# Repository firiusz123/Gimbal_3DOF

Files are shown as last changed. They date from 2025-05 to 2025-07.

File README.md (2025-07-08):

# Gimbal_3DOF

---

## 📖 Project Description

**Gimbal 3DOF** is a three-axis camera stabilization system (pitch, roll, yaw) designed for integration with drones and small aerial platforms. The goal of the project was to create a modular, lightweight, energy-efficient gimball, for the Project classes of AGH university of science and technology course , Mechatronic Design . The system uses an IMU and servos, controlled by an STM32 microcontroller in the custom PCB , and by Arduino Mega within the prototype , both running with FreeRTOS. A Python-based graphical user interface (GUI) is also provided for testing and interaction. The working model present on the provided photos is a prototype that doesnt have the custom PCB that has been designed

---

## ⚙️ Features

- 3-axis stabilization: **Pitch**, **Roll**, and **Yaw**
- Supports cameras up to **200 g**
- Compact size: **30 × 10 × 15 cm**
- Lightweight design: **~200 g**
- Power consumption: **~900 mA** estimated for worst case scenario
- UART-based communication
- Rubber-based vibration damping system
- Python GUI for testing and position control
- FreeRTOS-based multithreaded control system
- Optimized weight distribution and center of mass

---

## 🧾 Requirements

### Hardware with custom PCB

| Component | Model / Notes |
|---|---|
| Microcontroller | STM32G431CBT6 |
| IMU Sensor | IMU 9DOF v2.0 |
| Servos | Feetech FS510R ×3 |
| Oscillator | 8 MHz WE-XTAL |
| PCB | Custom PCB or Arduino prototype  |
| Logic level shifters| 2× SN74LV1T34 |
| Vibration dampers | Silicone-based, hand-cut |

### Hardware of Prototype

| Component | Model / Notes |
|---|---|
| Board | Arduino Mega |
| IMU Sensor | IMU 9DOF v2.0 |
| Servos | Feetech FS510R ×3 |
| LM7805 | 5v Linear Stabilizator |
| 7.4 v lipo | a small lipo battery 2s |

### Connection scheme for the prototype 
#### 🧭 Servo Motor Pinout

| Servo Axis | Signal Pin (Arduino) | VCC (5 V from LM7805) | GND (Common Ground) |
|---|---|---|---|
| Roll | D9 | LM7805 OUT | LM7805 GND |
| Pitch | D10 | LM7805 OUT | LM7805 GND |
| Yaw | D2 | LM7805 OUT | LM7805 GND |

---

### ⚡ Power Supply Setup (LM7805)

| LM7805 Pin | Connects To |
|---|---|
| **IN** | 7.4 V battery (+) |
| **OUT** | - 5 V to all Servo VCC pins  <br> - 5 V to Arduino **VIN** *(optional)* |
| **GND** | - Battery (–) <br> - All Servo GND pins <br> - Arduino **GND** |

The connection from 5v to vin is optional since the power to arduino is also delivered via cable that sends the commands to arduino 

### Software

- FreeRTOS (embedded)
- Python GUI for control and testing
- Source code (C / Arduino)

---

## 💻 Usage

1. Connect all components using the provided PCB or wire manually according to the schematic.
2. Upload the firmware from the `Arduino_example\GimbalControl1` directory to the Arduino.
3. Launch the GUI from the `python_gui` directory for testing and IMU visualization.
4. The gimbal continuously reads IMU data and stabilizes the camera accordingly.
5. You can also send specific positions for the gimbal to hold using the GUI.

---

## 🧩 Hardware & Software

**Hardware:**
- FS510R servos provide accurate positioning with low power consumption.
- IMU 9DOF v2.0 offers compact size, low power, and acceptable precision.
- Custom PCB integrates all components for clean wiring and scalability.
- Silicone dampers mitigate mechanical vibrations from drone operation.

**Software:**
- Based on FreeRTOS – enables independent control of each axis.
- Python GUI allows sending positions, reading IMU data, and system testing.
- All code is available in the `Arduino_example` and `python_gui` directories.

---

## 📈  Simulations

The project included modal simulations (FEM) using Siemens NX. These simulations helped with:

- Identifying modal frequencies (especially around **700 Hz**) and ensuring the control loop (**100 Hz**) avoids them.
- Optimizing the gimbal’s mass distribution and weight balancing.
- Evaluating dynamic response under two critical configurations (extreme pitch/yaw).

Simulation results guided mechanical redesigns and ensured robustness in real-world operation.

---

## 🖼️ Prototype Images

### ✅ Final prototype mounted on a drone:
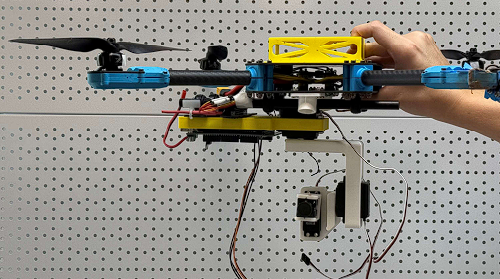
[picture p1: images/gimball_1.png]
Gimbal mounted on drone

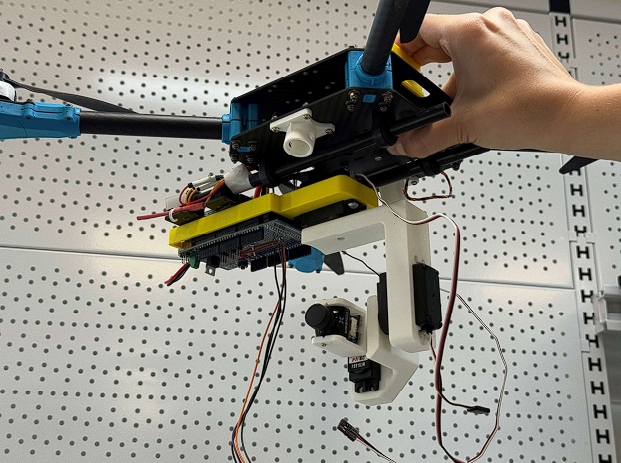
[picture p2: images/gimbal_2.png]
Gimbal mounted on drone

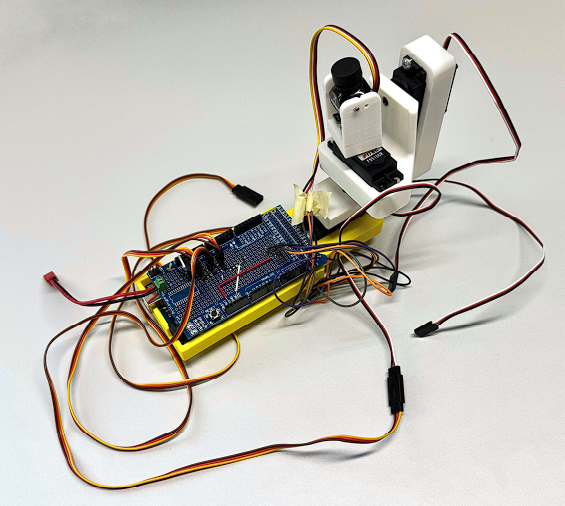
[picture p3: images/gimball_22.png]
Gimbal mounted on drone


### 🛠️ Assembled components:
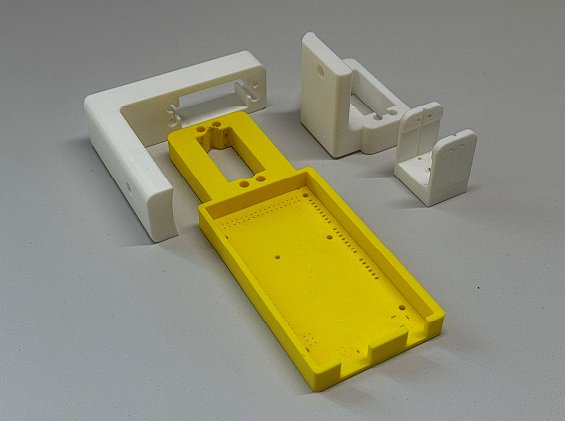
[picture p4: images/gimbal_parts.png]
Gimbal parts


### 🖥️ GUI for testing and visualization:
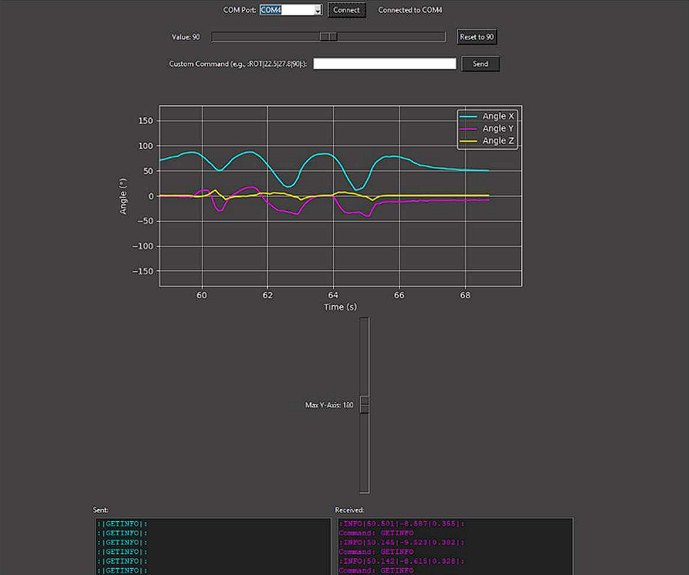
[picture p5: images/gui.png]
GUI


---

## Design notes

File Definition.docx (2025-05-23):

Definition

System for image stabilization and data transfer to higher up hardware in flights

Aspects of the problem:

System functions:

-3dof stabilization

-image acquisition

-image transfer

-water resistance

-dust resistance

-Passive vibration resistance

Properties of 3dof stabilization:

- Type of motors used for movement
- Type of device or devices used for feedback loop
- Control system

Properties of image acquisition:

- Colour range
- Focus
- Resolution
- Dos it include

Properties of image transfer:

- Transfer protocol
- Transfer speed

Properties of Water resistance:

- Grade of water resistance

Properties of dust resistance:

- Grade of dust resistance

Properties of passive vibration resistance:

- Bulletproof

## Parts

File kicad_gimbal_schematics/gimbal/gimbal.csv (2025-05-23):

Reference | Value | Datasheet | Footprint | Qty | DNP
C1,C2,C3 | C | ~ | Capacitor_SMD:C_0805_2012Metric | 3
C4,C5,C6 | 100nF | ~ | Capacitor_SMD:C_0805_2012Metric | 3
C7 | 4.7 μF | ~ | Capacitor_SMD:C_0805_2012Metric | 1
C8 | 10 nF | ~ | Capacitor_SMD:C_0805_2012Metric | 1
C9 | 1 μF | ~ | Capacitor_SMD:C_0805_2012Metric | 1
C10 | 100 nF | ~ | Capacitor_SMD:C_0805_2012Metric | 1
C11 | +1 μF | ~ | Capacitor_SMD:C_0805_2012Metric | 1
C12,C13 | 10 pF | ~ | Capacitor_SMD:C_0805_2012Metric | 2
D1 | D | ~ | Diode_SMD:D_0805_2012Metric | 1
J1 | Conn_01x04_Pin_IMU | ~ | Connector_JST:JST_PH_B4B-PH-K_1x04_P2.00mm_Vertical | 1
J2 | Conn_01x04_Pin | ~ | Connector_JST:JST_PH_B4B-PH-K_1x04_P2.00mm_Vertical | 1
M1,M2,M3 | Motor_Servo | http://forums.parallax.com/uploads/attachments/46831/74481.png | Connector_PinHeader_2.54mm:PinHeader_1x03_P2.54mm_Vertical | 3
R1 | 45Ω | ~ | Resistor_SMD:R_0805_2012Metric | 1
SW1 | SW_Slide_DPDT | ~ | Button_Switch_THT:SW_CK_JS202011CQN_DPDT_Straight | 1
SW3 | SW_Push | ~ | Button_Switch_SMD:SW_Push_1P1T_NO_6x6mm_H9.5mm | 1
U1 | STM32G431CBTx | https://www.st.com/resource/en/datasheet/stm32g431cb.pdf | Package_QFP:LQFP-48_7x7mm_P0.5mm | 1
U2 | LT1761-3.3 | https://www.analog.com/media/en/technical-documentation/data-sheets/1761sff.pdf | Package_TO_SOT_SMD:TSOT-23-5 | 1
U3,U4 | SN74LV1T34DBV | https://www.ti.com/lit/ds/symlink/sn74lv1t34.pdf | Package_TO_SOT_SMD:SOT-23-5 | 2
Y1 | 8 MHz | ~ | Crystal:Crystal_HC18-U_Vertical | 1

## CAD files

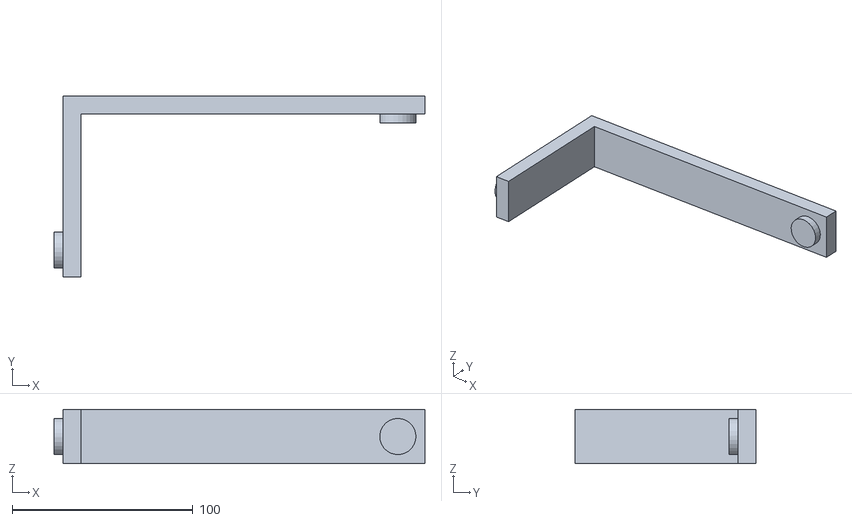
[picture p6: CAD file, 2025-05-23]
Gimbal_initial_simulation/STL_Hell/arm_1.stl
205.0 x 100.0 x 30.0

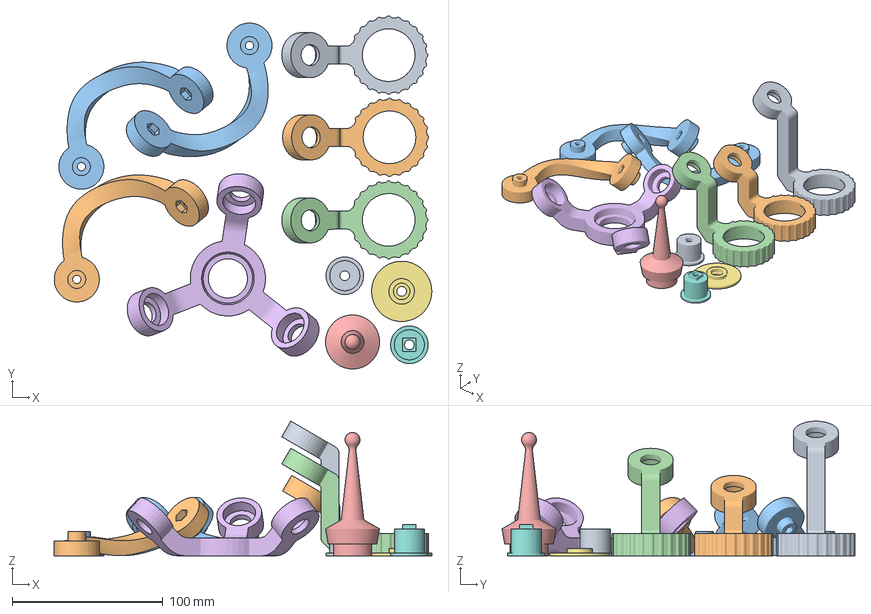
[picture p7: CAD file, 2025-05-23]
SPM_project.3mf
250.7 x 234.5 x 89.5 mm
Arm 1.STL
Arm 3.STL
Arm(x3).STL x 3
Arm 2.STL
Pin.STL
Center Platform.STL
End Plate.STL
Shaft 2.STL
Shaft 3.STL

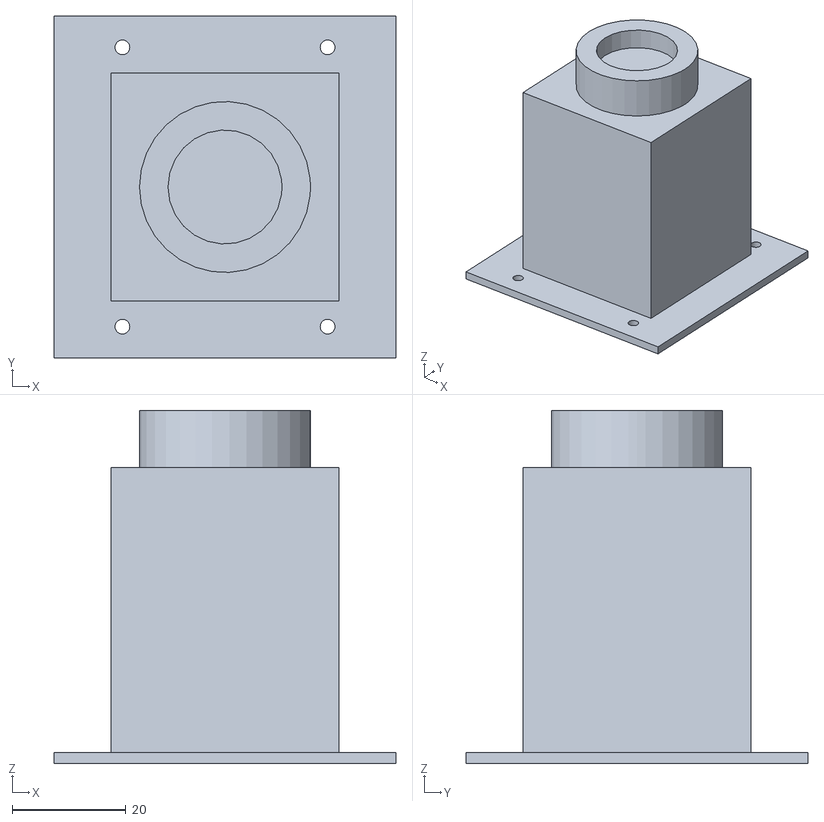
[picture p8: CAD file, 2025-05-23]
Gimbal_initial_simulation/STL_Hell/base.stl
60.0 x 60.0 x 62.0

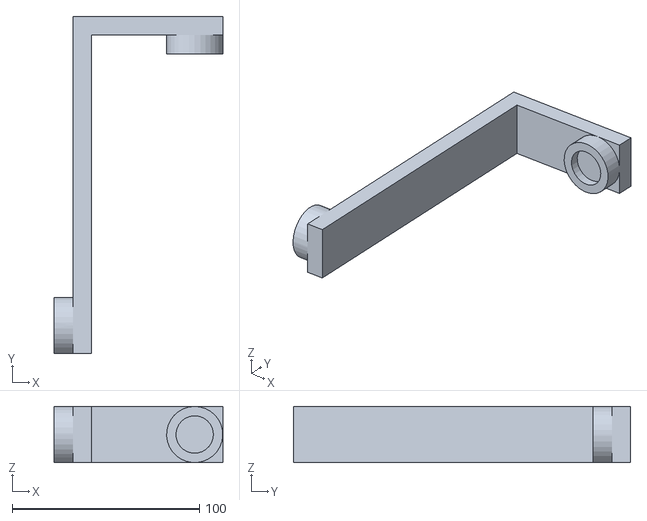
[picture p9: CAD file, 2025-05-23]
Gimbal_initial_simulation/STL_Hell/arm_2.stl
90.0 x 180.0 x 30.0

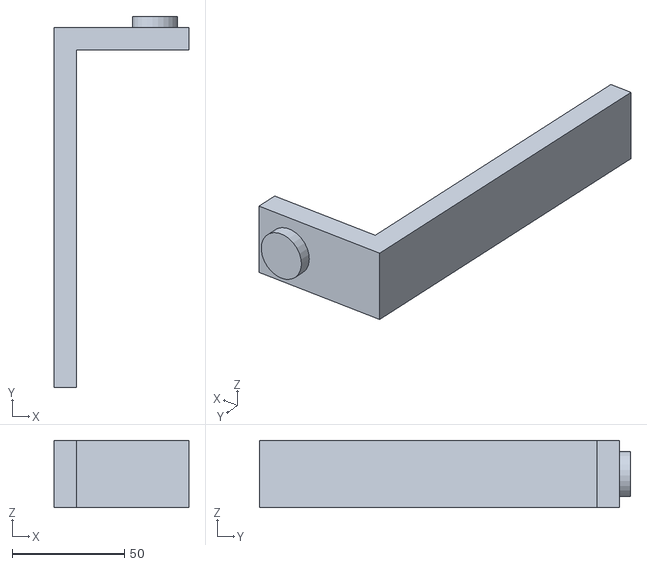
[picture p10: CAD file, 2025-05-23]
Gimbal_initial_simulation/STL_Hell/platform.stl
60.0 x 165.0 x 30.0

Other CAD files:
Fusion 360 Assembly/Gimbal v2.f3z

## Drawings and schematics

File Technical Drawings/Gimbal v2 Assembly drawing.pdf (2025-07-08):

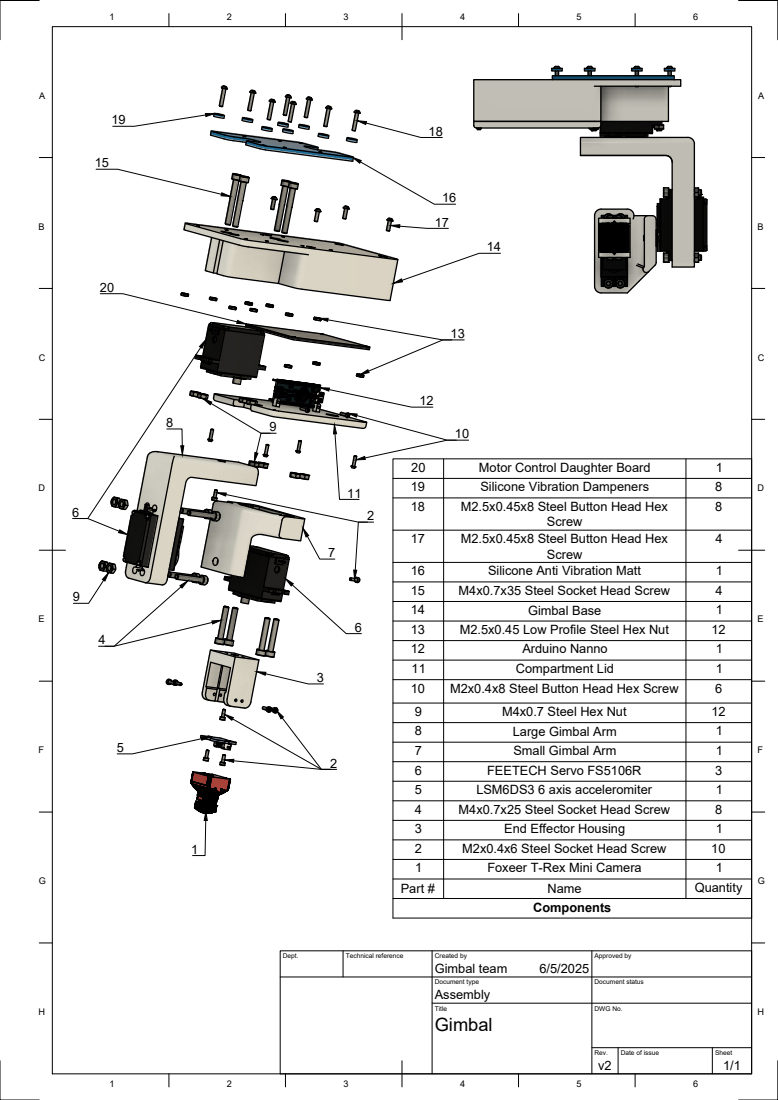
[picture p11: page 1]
Dept.; Technical reference; Created by; Approved by; Document type; Document status; Title; DWG No.; Rev.; Date of issue; Sheet; Gimbal team; Part #; Name; Quantity; Foxeer T-Rex Mini Camera; M2x0.4x6 Steel Socket Head Screw; End Effector Housing; M4x0.7x25 Steel Socket Head Screw; LSM6DS3 6 axis acceleromiter; FEETECH Servo FS5106R; Small Gimbal Arm; Large Gimbal Arm; M4x0.7 Steel Hex Nut; M2x0.4x8 Steel Button Head Hex Screw; Compartment Lid; Arduino Nanno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

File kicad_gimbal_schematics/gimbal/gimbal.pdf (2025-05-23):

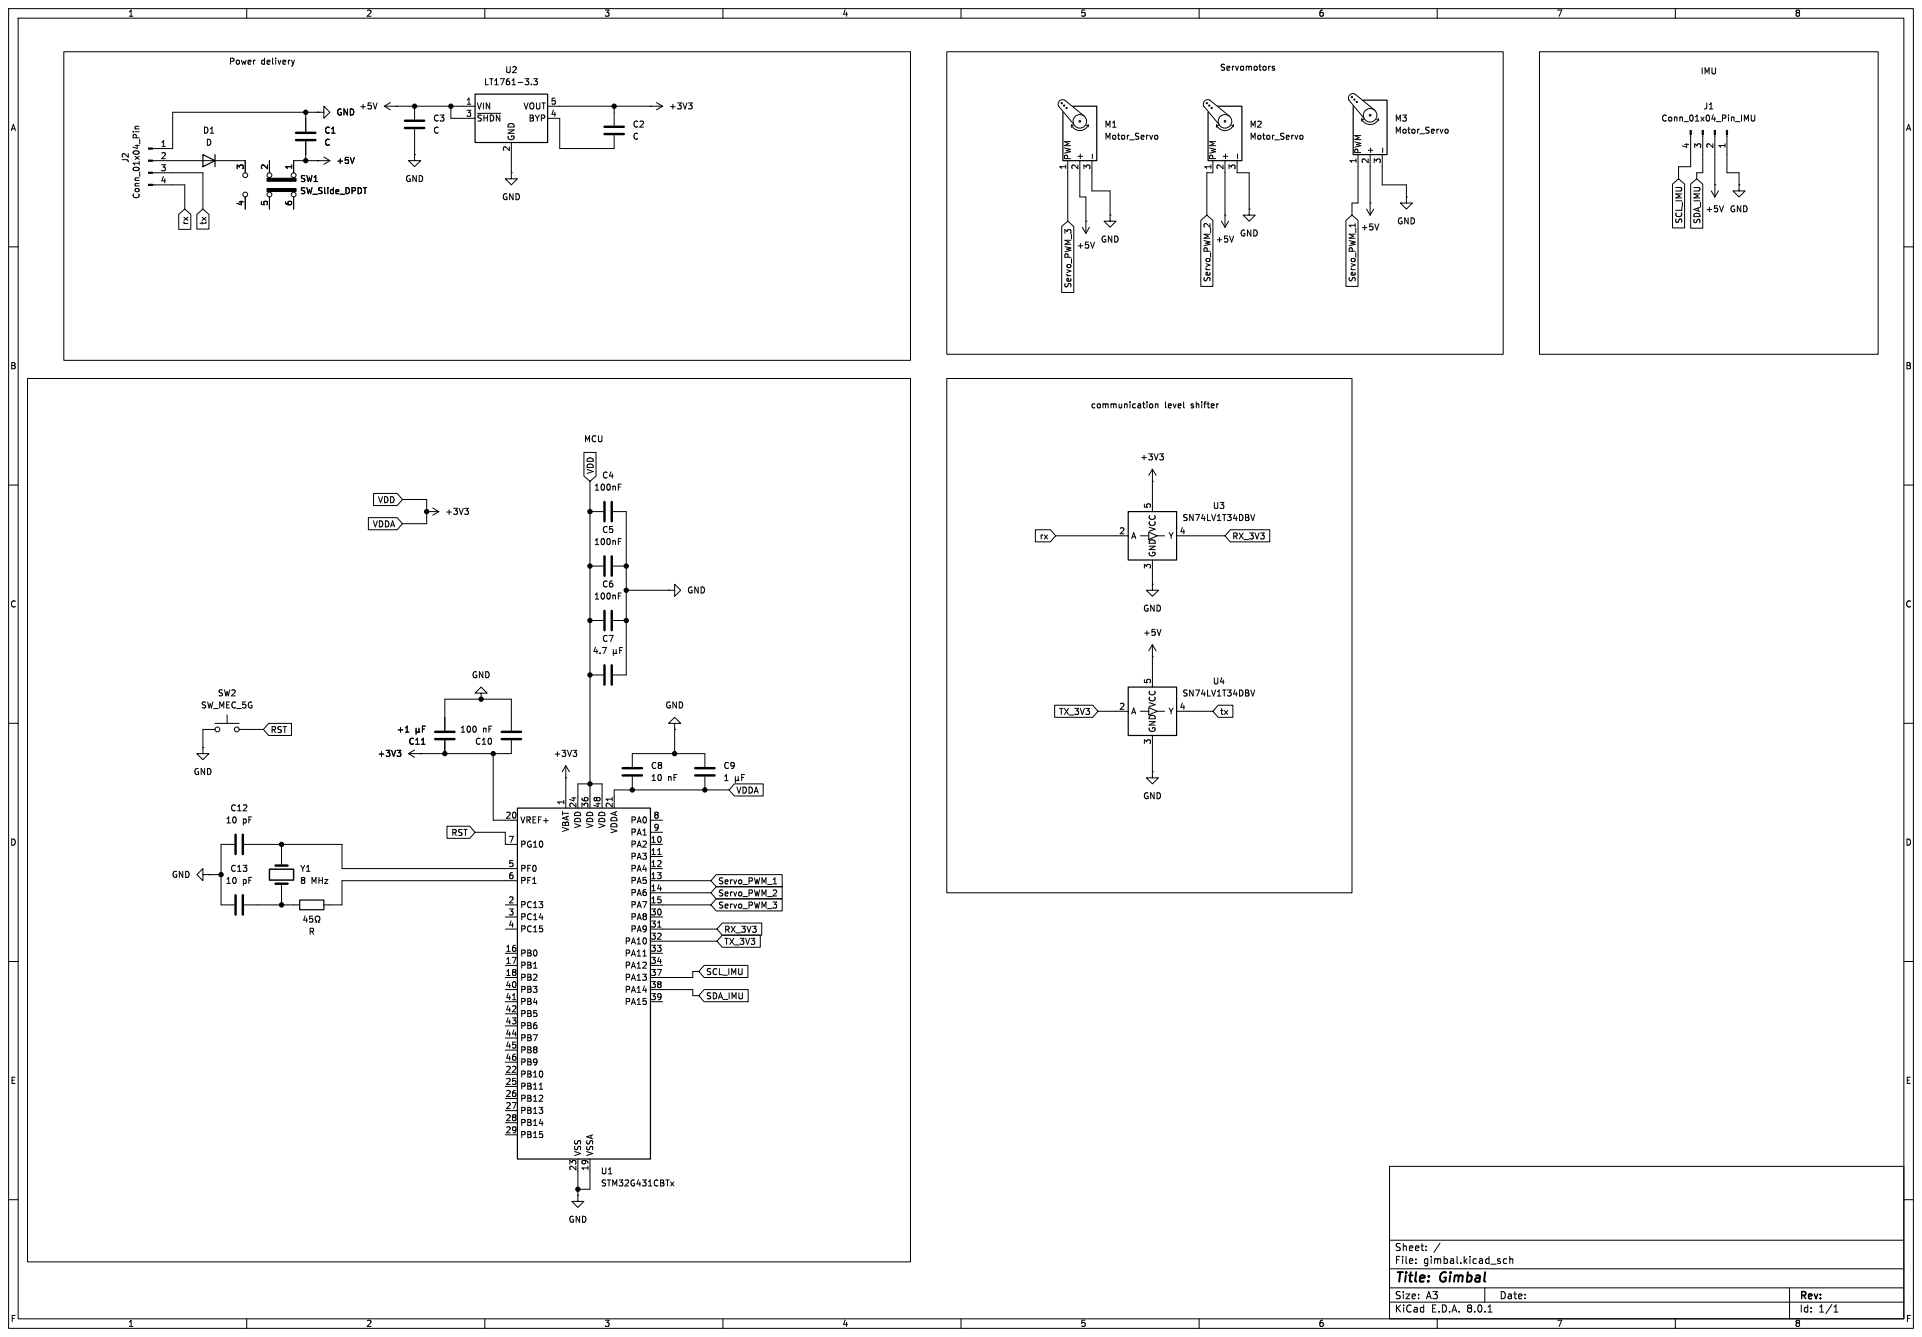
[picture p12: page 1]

Id: 1/1 Title: Gimbal File: gimbal.kicad_sch Sheet: /

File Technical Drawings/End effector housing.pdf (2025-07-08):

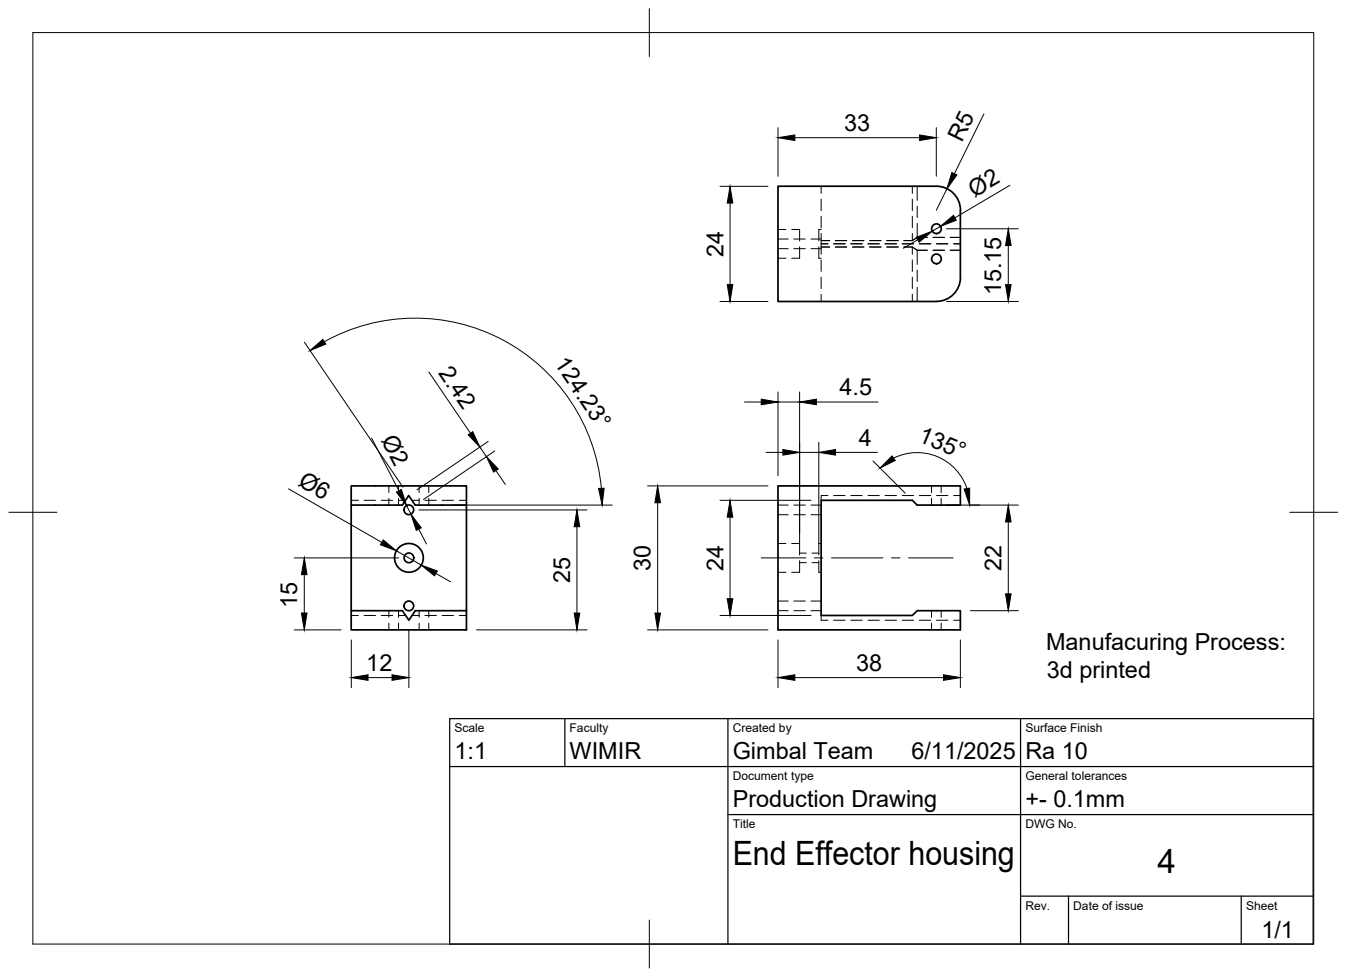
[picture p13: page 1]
Manufacuring Process: 3d printed

Scale 1:1 | Faculty WIMIR | Created by Gimbal Team 6/11/2025 | Surface Finish Ra 10

Document type Production Drawing | General tolerances +- 0.1mm

Title End Effector housing | DWG No. 4

Rev. | Date of issue | Sheet 1/1

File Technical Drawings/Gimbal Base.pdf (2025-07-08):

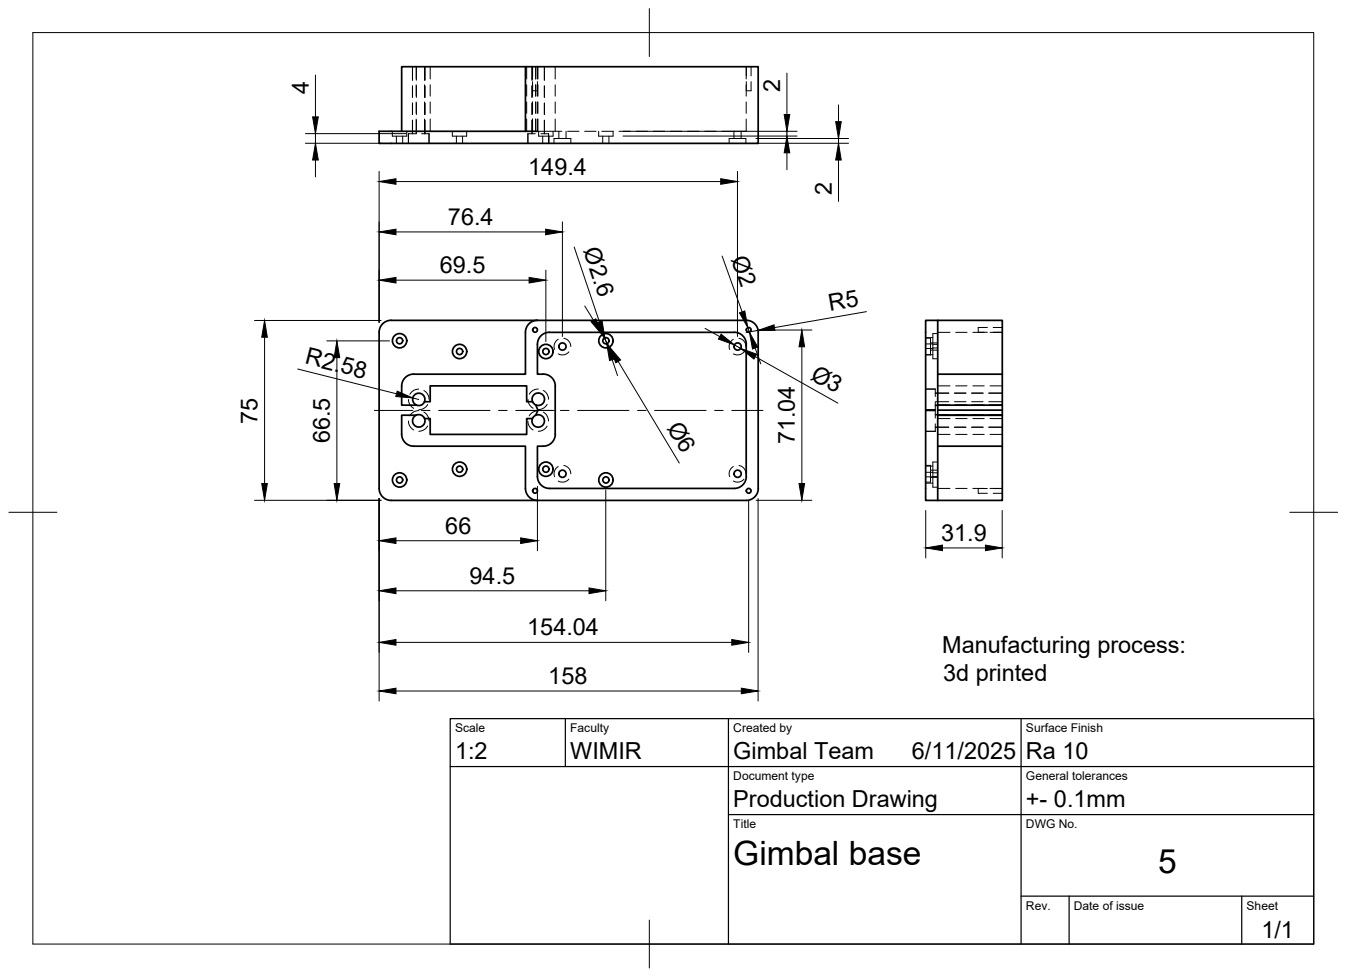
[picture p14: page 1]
Manufacturing process: 3d printed

Scale 1:2 | Faculty WIMIR | Created by Gimbal Team 6/11/2025 | Surface Finish Ra 10

Document type Production Drawing | General tolerances +- 0.1mm

Title Gimbal base | DWG No. 5

Rev. | Date of issue | Sheet 1/1

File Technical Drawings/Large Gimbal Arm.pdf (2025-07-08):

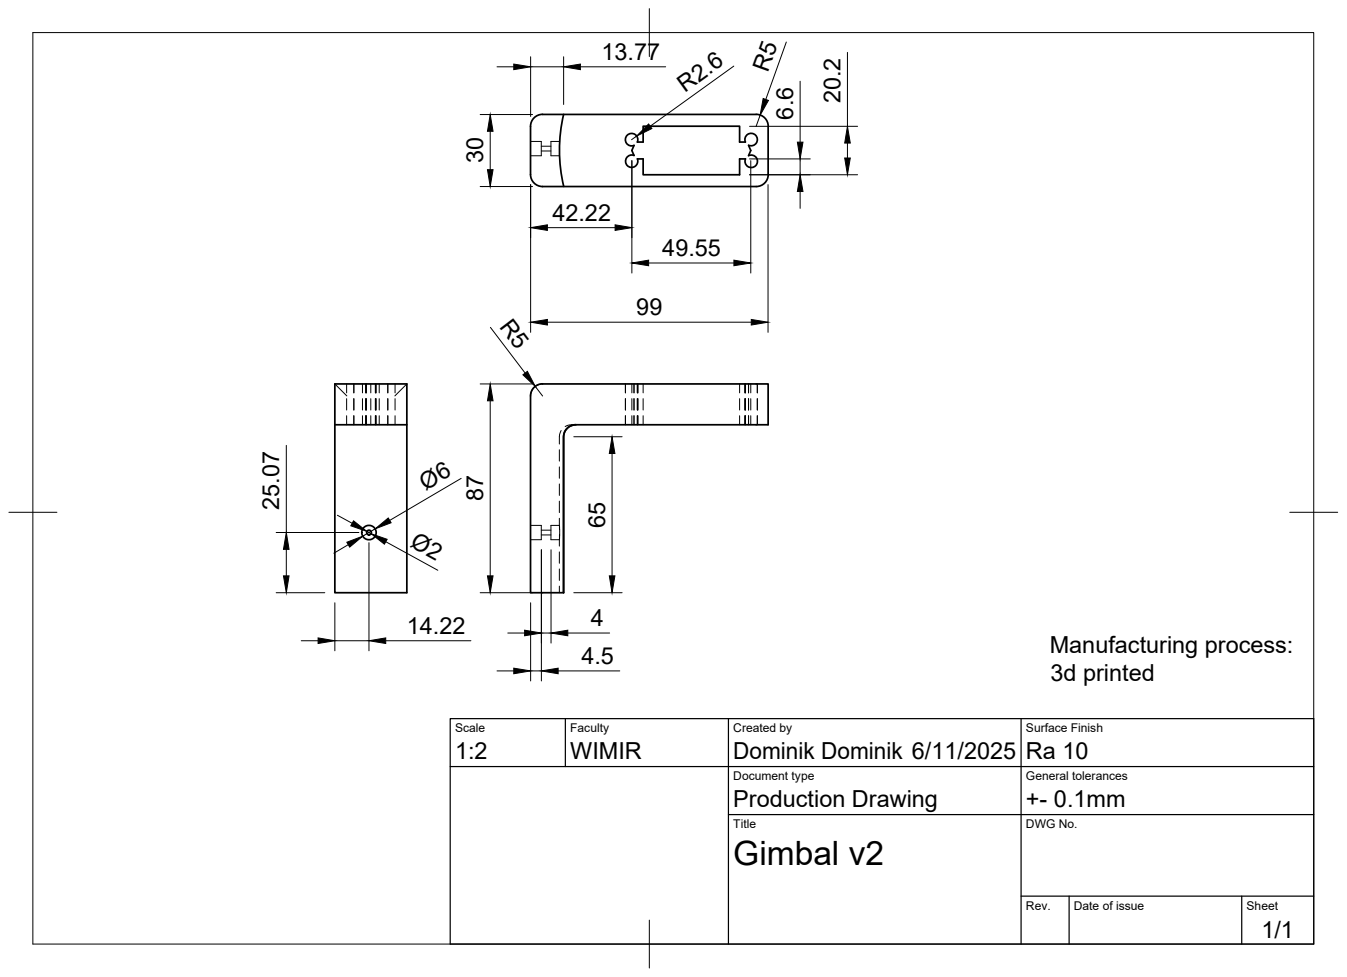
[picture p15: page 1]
Manufacturing process: 3d printed

Scale 1:2 | Faculty WIMIR | Created by Dominik Dominik 6/11/2025 | Surface Finish Ra 10

Document type Production Drawing | General tolerances +- 0.1mm

Title Gimbal v2 | DWG No.

Rev. | Date of issue | Sheet 1/1

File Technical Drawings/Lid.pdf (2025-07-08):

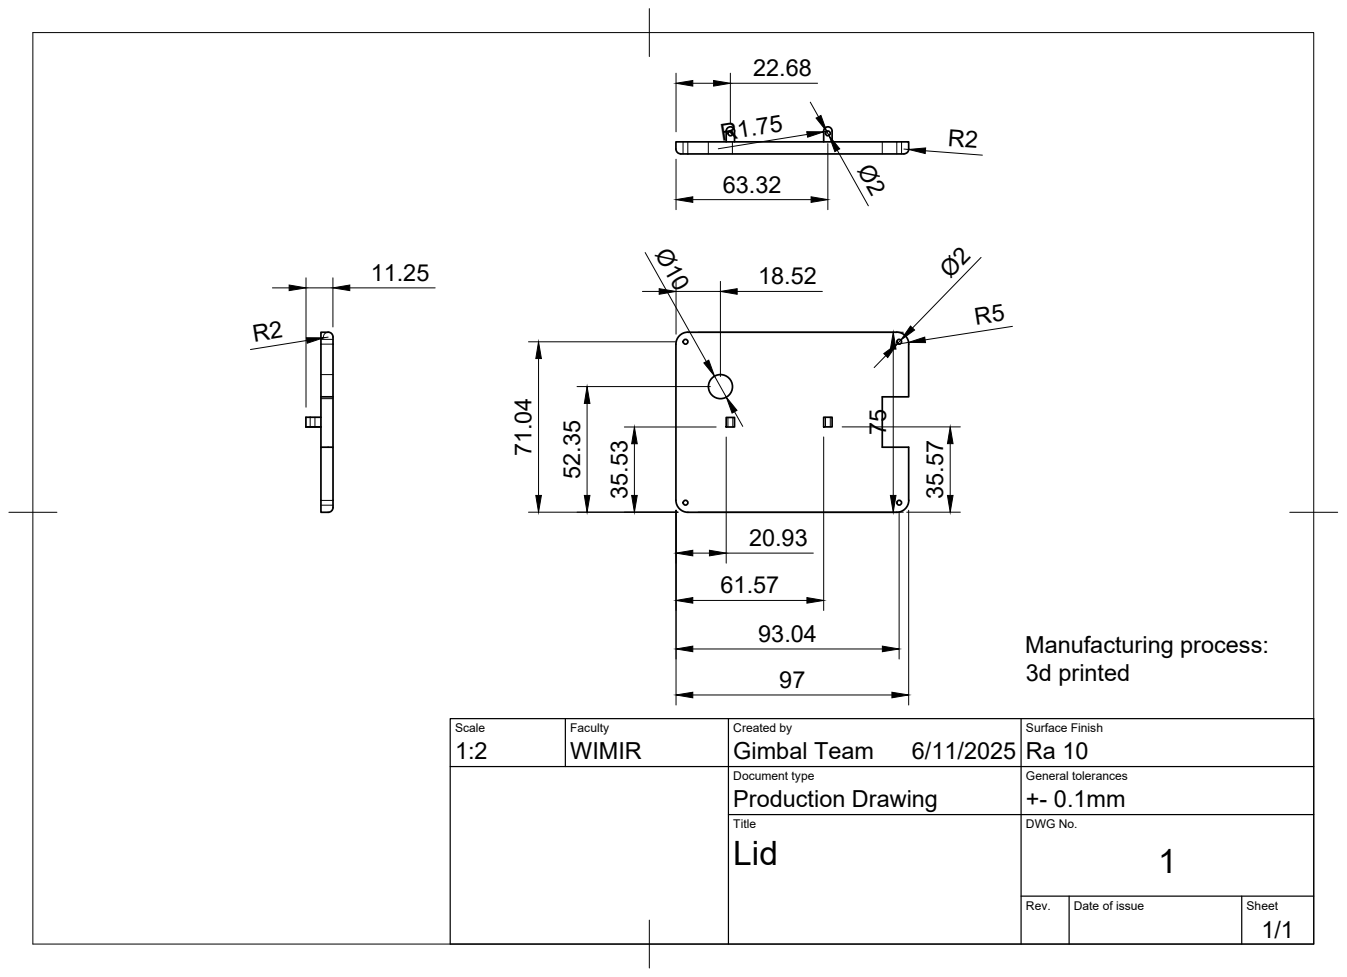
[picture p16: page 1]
Manufacturing process: 3d printed

Scale 1:2 | Faculty WIMIR | Created by Gimbal Team 6/11/2025 | Surface Finish Ra 10

Document type Production Drawing | General tolerances +- 0.1mm

Title Lid | DWG No. 1

Rev. | Date of issue | Sheet 1/1

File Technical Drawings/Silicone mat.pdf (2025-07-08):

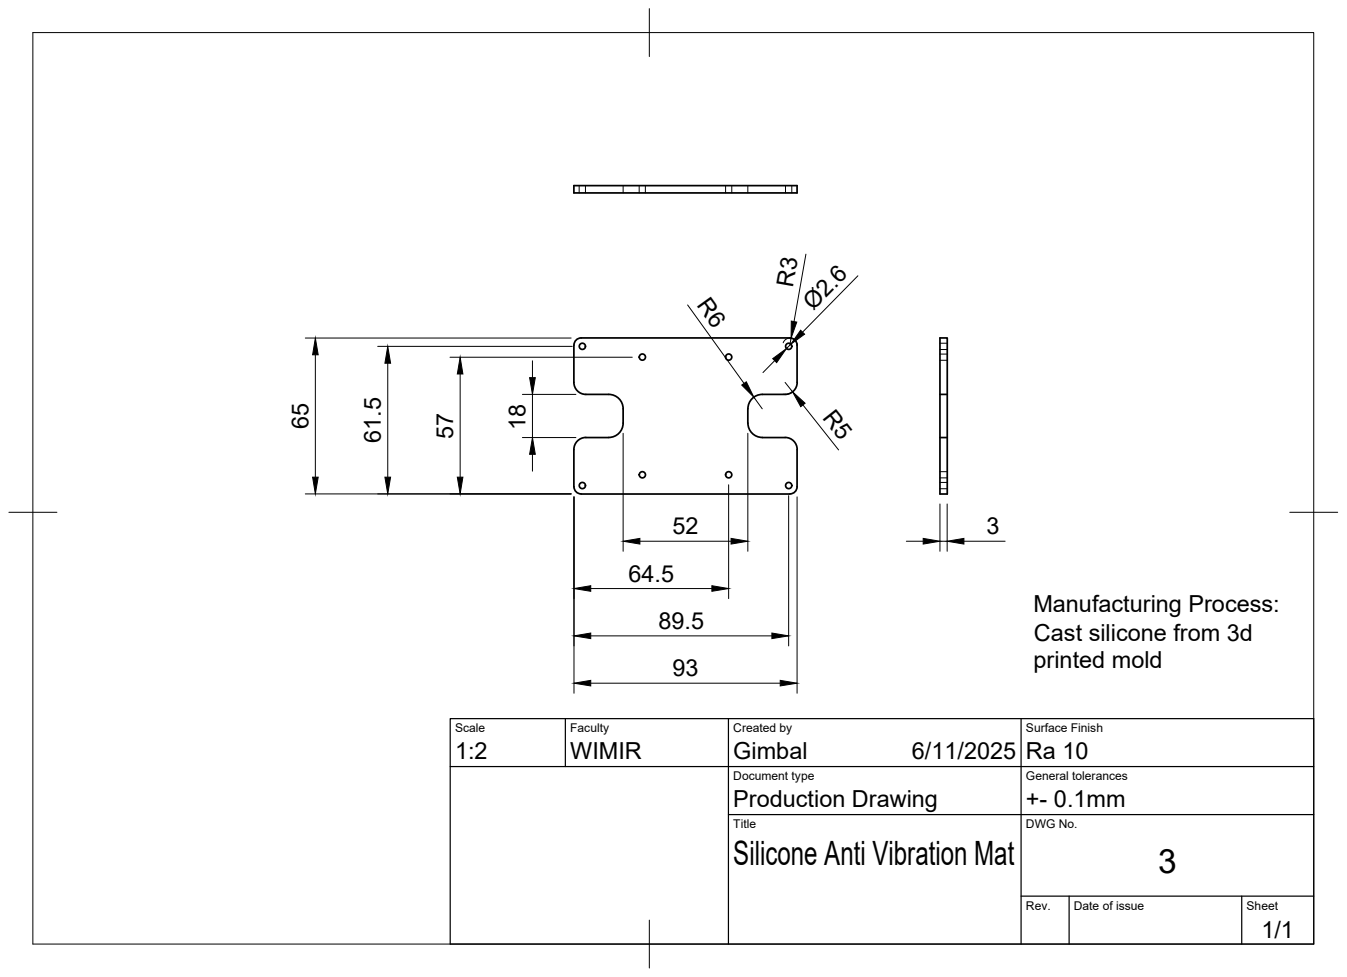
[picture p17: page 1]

Manufacturing Process:
Cast silicone from 3d
printed mold

Scale 1:2 | Faculty WIMIR | Created by Gimbal 6/11/2025 | Surface Finish Ra 10

Document type Production Drawing | General tolerances +- 0.1mm

Title Silicone Anti Vibration Mat | DWG No. 3

Rev. | Date of issue | Sheet 1/1

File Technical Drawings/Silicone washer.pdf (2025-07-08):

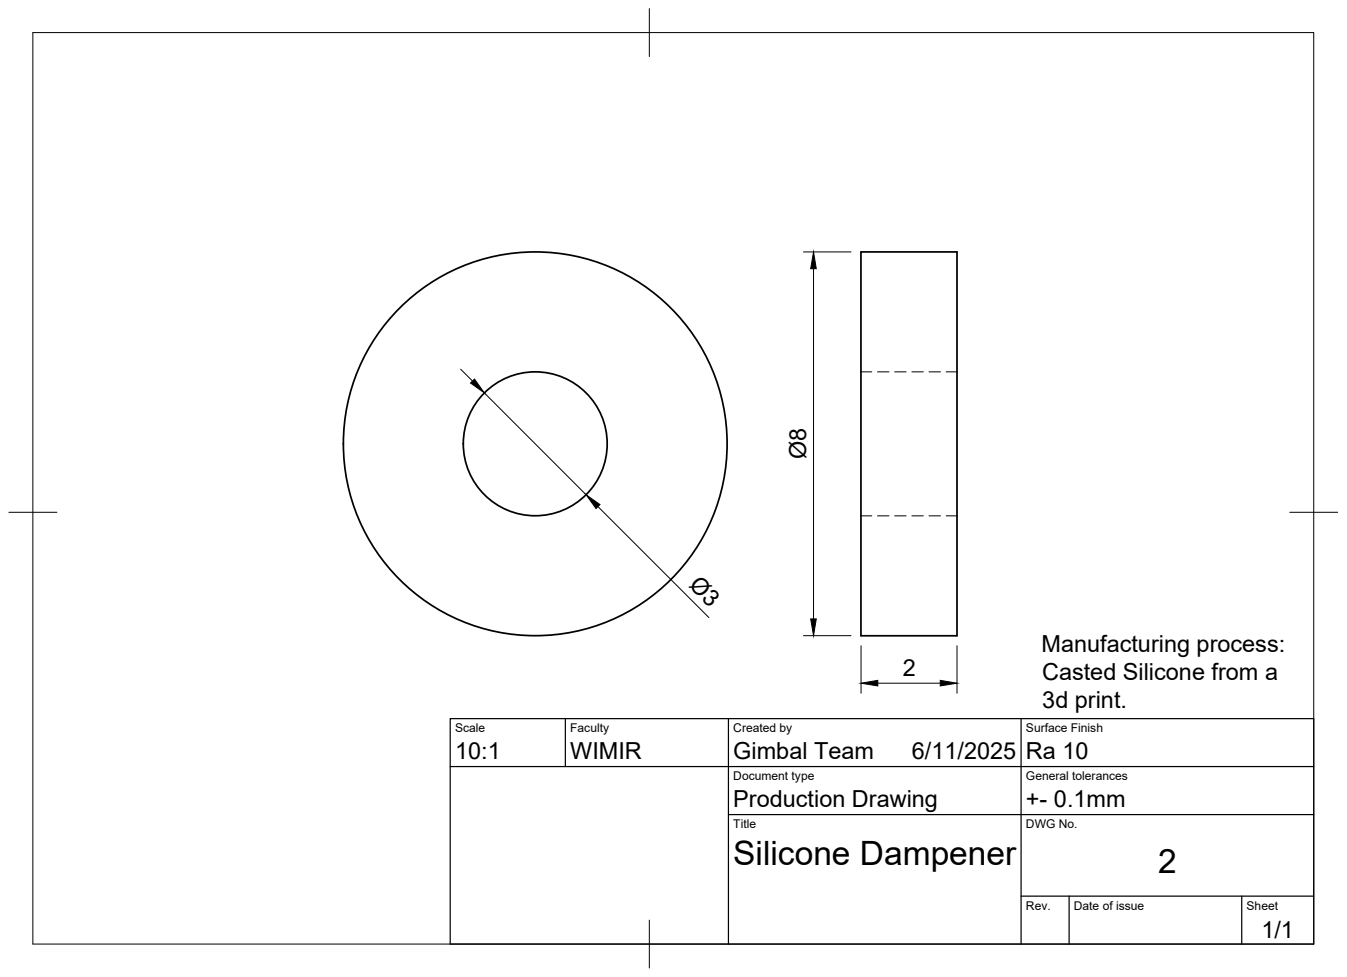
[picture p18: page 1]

Manufacturing process:
Casted Silicone from a
3d print.

Scale 10:1 | Faculty WIMIR | Created by Gimbal Team 6/11/2025 | Surface Finish Ra 10

Document type Production Drawing | General tolerances +- 0.1mm

Title Silicone Dampener | DWG No. 2

Rev. | Date of issue | Sheet 1/1

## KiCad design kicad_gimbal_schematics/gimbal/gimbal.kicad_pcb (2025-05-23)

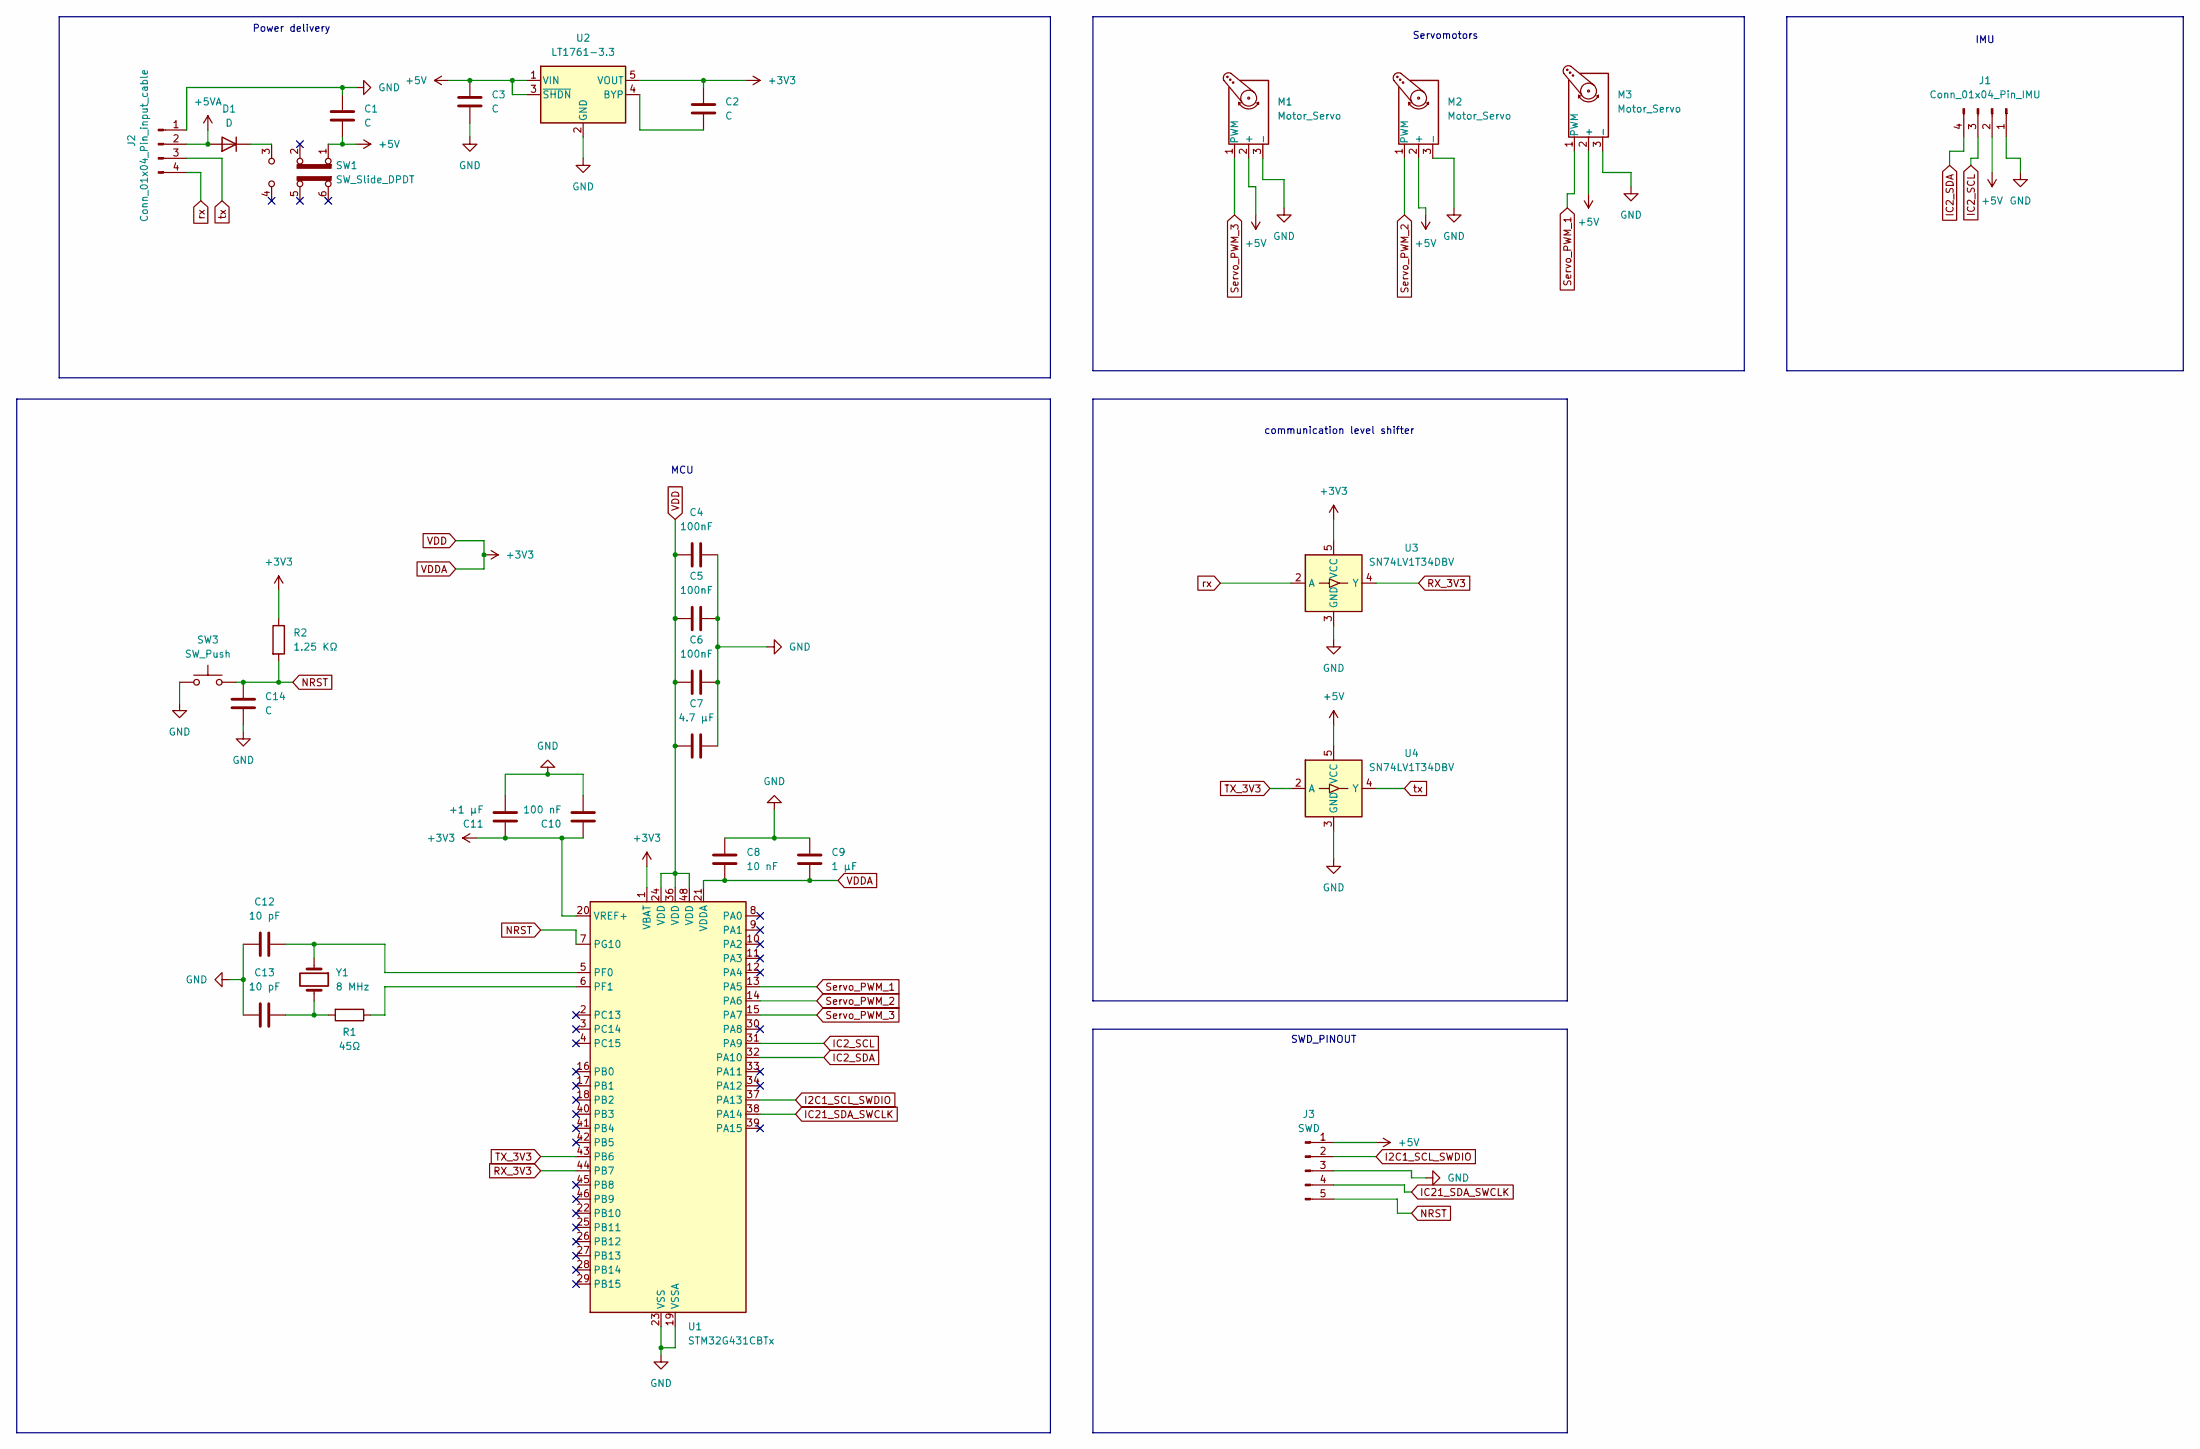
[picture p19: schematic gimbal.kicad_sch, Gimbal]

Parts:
C1, C2, C3: C; C_0805_2012Metric
C4, C5, C6: 100nF; C_0805_2012Metric
C7: 4.7 μF; C_0805_2012Metric
C8: 10 nF; C_0805_2012Metric
C9: 1 μF; C_0805_2012Metric
C10: 100 nF; C_0805_2012Metric
C11: +1 μF; C_0805_2012Metric
C12, C13: 10 pF; C_0805_2012Metric
C14: C; C_0805_2012Metric_Pad1.18x1.45mm_HandSolder
D1: D; D_0805_2012Metric
J1: Conn_01x04_Pin_IMU; PinHeader_1x04_P2.54mm_Vertical
J2: Conn_01x04_Pin_input_cable; PinHeader_1x04_P2.54mm_Vertical
J3: SWD; PinHeader_1x05_P2.54mm_Vertical
M1, M2, M3: Motor_Servo; PinHeader_1x03_P2.54mm_Vertical
R1: 45Ω; R_0805_2012Metric
R2: 1.25 KΩ; R_0805_2012Metric_Pad1.20x1.40mm_HandSolder
SW1: SW_Slide_DPDT; SW_CK_JS202011CQN_DPDT_Straight
SW3: SW_Push; SW_SPST_B3U-1000P
U1: STM32G431CBTx; LQFP-48_7x7mm_P0.5mm
U2: LT1761-3.3; TSOT-23-5
U3, U4: SN74LV1T34DBV; SOT-23-5
Y1: 8 MHz; Crystal_SMD_0603-2Pin_6.0x3.5mm

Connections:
+5V: C1.1, C3.1, J1.2, J3.1, M1.2 (+), M2.2 (+), M3.2 (+), SW1.1 (A), U2.1 (VIN), U2.3 (~SHDN), U4.5 (VCC)
+5VA: D1.2 (A), J2.2
GND: C1.2, C3.2, C4.1, C5.1, C6.1, C7.1, C8.1, C9.1, C10.1, C11.1, C12.2, C13.2, C14.2, J1.1, J2.1, J3.3, M1.3 (-), M2.3 (-), M3.3 (-), SW3.1, U1.19 (VSSA), U1.23 (VSS), U1.35 (VSS), U1.47 (VSS), U2.2 (GND), U3.3 (GND), U4.3 (GND)
I2C1_SCL_SWDIO: J3.2, U1.37 (PA13)
IC2_SCL: J1.3, U1.31 (PA9)
IC2_SDA: J1.4, U1.32 (PA10)
IC21_SDA_SWCLK: J3.4, U1.38 (PA14)
NRST: C14.1, J3.5, R2.2, SW3.2, U1.7 (PG10)
unnamed: C13.1, R1.2, Y1.2
unnamed: D1.1 (K), SW1.3 (C)
unnamed: C12.1, U1.5 (PF0), Y1.1
unnamed: R1.1, U1.6 (PF1)
unnamed: C2.2, U2.4 (BYP)
RX_3V3: U1.44 (PB7), U3.4 (Y)
Servo_PWM_1: M3.1 (PWM), U1.13 (PA5)
Servo_PWM_2: M2.1 (PWM), U1.14 (PA6)
Servo_PWM_3: M1.1 (PWM), U1.15 (PA7)
TX_3V3: U1.43 (PB6), U4.2 (A)
VDD: C2.1, C4.2, C5.2, C6.2, C7.2, C8.2, C9.2, C10.2, C11.2, R2.1, U1.1 (VBAT), U1.20 (VREF+), U1.21 (VDDA), U1.24 (VDD), U1.36 (VDD), U1.48 (VDD), U2.5 (VOUT), U3.5 (VCC)
rx: J2.4, U3.2 (A)
tx: J2.3, U4.4 (Y)

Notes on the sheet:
communication level shifter
SWD_PINOUT
Servomotors
IMU
MCU
Power delivery

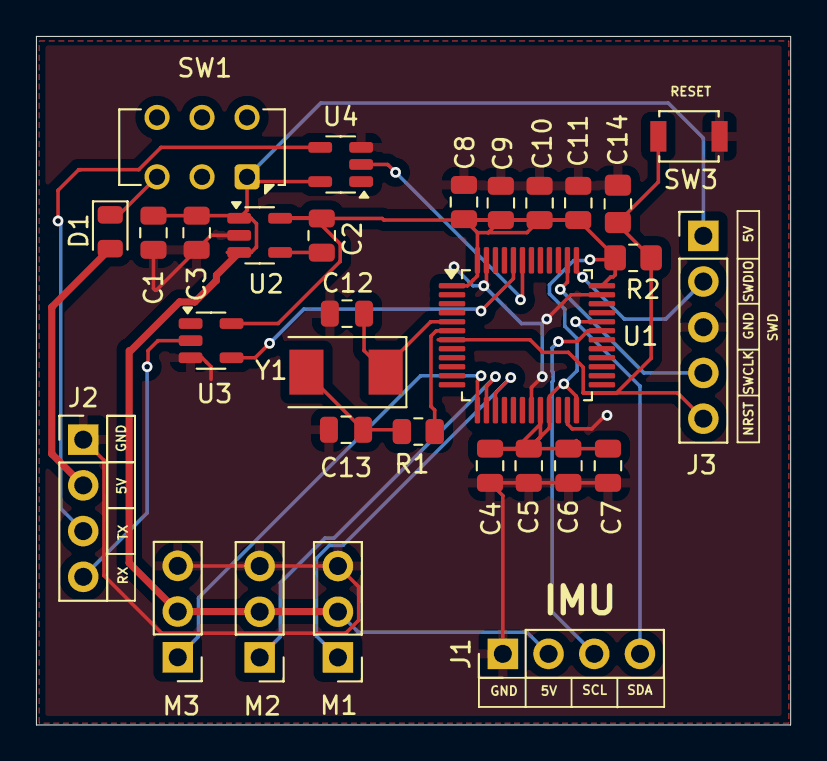
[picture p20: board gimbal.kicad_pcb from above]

Board: 2 copper layers, 41.9 x 38.2 mm, 30 parts (0 on the bottom side), 21 nets.

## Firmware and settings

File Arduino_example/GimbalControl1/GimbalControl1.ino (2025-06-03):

#include <Arduino_FreeRTOS.h>
#include <semphr.h>
#include <Wire.h>
#include <Arduino_LSM6DS3.h>
#include <Servo.h>

// Servo control
Servo servoRoll;
Servo servoPitch;
Servo servoYaw;

const int SERVO_ROLL_PIN = 9;
const int SERVO_PITCH_PIN = 10;
const int SERVO_YAW_PIN = 2;

// PID parameters (tune individually per axis)
float Kp[3] = {1.5, 1.5, 1};
float Ki[3] = {0.0, 0.0, 0};
float Kd[3] = {0.1, 0.1, 0};

// PID state
float errorSum[3] = {0, 0, 0};
float lastError[3] = {0, 0, 0};

// Angles: 0 = Roll, 1 = Pitch, 2 = Yaw
float measuredAngles[3] = {0, 0, 0};
float desiredAngles[3]  = {0, 0, 0};  // Set externally (e.g. via Serial)
float fusedAngle[3] = {0, 0, 0};
// value for complementary filter
static float acc_measure[3];
static float mag_measure[3];
static float pidOutput[3], error[3], dError[3];
static float  acc_x, acc_y, acc_z;
static float  mag_x, mag_y, mag_z;
static float dt;

// Static variables to keep previous magnetometer values for filtering
static float prev_mag_x = 0.0;
static float prev_mag_y = 0.0;
static float prev_mag_z = 0.0;


const float MAG_THRESHOLD = 1;
const float alpha = 1;

unsigned long lastTime = 0;

/// defines 
#define PI  3.14159 
#define START_COMMAND_CHAR ':'
#define SEPARATE_VALUE_CHAR "|"

/////////////////// variables setting 

SemaphoreHandle_t dataSemaphore;  // Semaphore for data synchronization
SemaphoreHandle_t pass_angles_Semaphore;

bool SpecialCharacterCapturing = false;
unsigned long lastTransfer = 0;
#define MAX_VALUES 4 
#define TIMEOUT_MS 2000
char command[50];
int CommandIndex = 0;

///////////////////////////////////////
//sensor data config 

// Task to read serial data
void readSerialTask(void *pvParameters) 
{
    
    while (1) {
      
        while (Serial.available()) 
        {

            char c = Serial.read();

            if(millis() - lastTransfer > TIMEOUT_MS)
            {
                SpecialCharacterCapturing = false;    
            }

            if(c == START_COMMAND_CHAR)
            {
              if(SpecialCharacterCapturing)
              {
                //if already triggered it means it finished
                
                SpecialCharacterCapturing = false;
                //Serial.println(receivedData);
                xSemaphoreGive(dataSemaphore);
              }

              else
              {     
                //clearing data buffer and setting the character saving to true                           
                memset(command, 0, sizeof(command));
                CommandIndex = 0 ;
                SpecialCharacterCapturing = true;  
                lastTransfer = millis();            
              }

            }
            else if(SpecialCharacterCapturing)
            {
              command[CommandIndex++] = c;  
              
              
              
            }
            //Serial.println(receivedData);
        }

        vTaskDelay(10 / portTICK_PERIOD_MS);  // Small delay to avoid CPU overload
    }
}

// Task to write received serial data
void commandChecker(void *pvParameters) 
{
    while (1) {
        if (xSemaphoreTake(dataSemaphore, portMAX_DELAY) == pdTRUE) {
            //Serial.print("Received: ");
            //Serial.println(receivedData);

           // if (comm.length() > 2) {
                // Trim leading and trailing delimiters
                //String trimmed = receivedData.substring(0, receivedData.length() - 1);
                //Serial.println(receivedData);
                //receivedData.trim();
                //char command[50];
                //receivedData.toCharArray(command, sizeof(command));
                

                char *token = strtok(command, SEPARATE_VALUE_CHAR);
                char *commandType = token;
                
                Serial.print("Command: ");
                Serial.println(commandType);
                int valueIndex = 0;
                while ((token = strtok(NULL, SEPARATE_VALUE_CHAR)) != NULL && valueIndex < MAX_VALUES) {
                    Serial.println(token);
                    desiredAngles[valueIndex++] = atof(token);
                }

                
                if(strcmp(commandType, "GETINFO") == 0)
                {
                  
                  xSemaphoreGive(pass_angles_Semaphore);
                }
                else if(commandType == "ROT")
                {
                  for (int i = 0; i < valueIndex; i++) 
                  {
                      Serial.print("Value ");
                      Serial.print(i + 1);
                      Serial.print(": ");
                      Serial.println(desiredAngles[i]);
                  }
                }
            //} else {
            //    Serial.println("Received data too short.");
            }

            
        }

        vTaskDelay(10 / portTICK_PERIOD_MS);
    
}

void control_Loop(void *pvParameters)
{
    static float acc_measure[3];
    static float mag_measure[3];
    static float pidOutput[3], error[3], dError[3];
    static float  acc_x, acc_y, acc_z;
    static float  mag_x, mag_y, mag_z;
    static float dt;

    // Static variables to keep previous magnetometer values for filtering
    static float prev_mag_x = 0.0;
    static float prev_mag_y = 0.0;
    static float prev_mag_z = 0.0;

    

    while (1)
    {
        // Timing
        unsigned long now = millis();
        dt = (now - lastTime) / 1000.0; // in seconds
        lastTime = now;
      //////

        if (IMU.accelerationAvailable()) 
        {
          IMU.readAcceleration(acc_x, acc_y, acc_z);
        }
        acc_measure[0] = acc_x;
        acc_measure[1] = acc_y;
        acc_measure[2] = acc_z;
        
      if (IMU.gyroscopeAvailable()) 
      {
        IMU.readGyroscope(mag_x, mag_y, mag_z);

        // Apply threshold filter to magnetometer values
        if (fabs(mag_x - prev_mag_x) < MAG_THRESHOLD) {
            mag_x = prev_mag_x;
        } else {
            prev_mag_x = mag_x;
            fusedAngle[0] += mag_x * dt;
        }

        if (fabs(mag_y - prev_mag_y) < MAG_THRESHOLD) {
            mag_y = prev_mag_y;
        } else {
            prev_mag_y = mag_y;
            fusedAngle[1] += mag_y * dt;
        }

        if (fabs(mag_z - prev_mag_z) < MAG_THRESHOLD) {
            mag_z = prev_mag_z;
        } else {
            prev_mag_z = mag_z;
            fusedAngle[2] += mag_z * dt;
        }
      }

          // Roll
          // Pitch
          // Yaw (will drift unless magnetometer used)

        // Calculate angle from accelerometer (in degrees)
        static float accRoll  = atan2(acc_y, acc_z) * 180.0 / PI;
        static float accPitch = atan2(-acc_x, sqrt(acc_y * acc_y + acc_z * acc_z)) * 180.0 / PI;

        // Complementary filter
        fusedAngle[0] = alpha * fusedAngle[0] + ((1 - alpha) * accRoll);
        fusedAngle[1] = alpha * fusedAngle[1] + ((1 - alpha) * accPitch);
        
        //Serial.print(":ANGLE|");
        //Serial.print(fusedAngle[0], 3);  // 3 decimal places
        //Serial.print("|");
        //Serial.print(fusedAngle[1], 3);
        //Serial.print("|");
        //Serial.print(fusedAngle[2], 3);
        //Serial.println("|:");

        // PID control for Roll, Pitch, Yaw
        for (int i = 0; i < 3; i++) {
            error[i] = desiredAngles[i] - fusedAngle[i];
            errorSum[i] += error[i] * dt;
            dError[i] = (error[i] - lastError[i]) / dt;

            pidOutput[i] = Kp[i] * error[i] + Ki[i] * errorSum[i] + Kd[i] * dError[i];
            lastError[i] = error[i];
        }

        // Convert to servo angles
        int rollAngle  = constrain(90 + pidOutput[0], 0, 180);
        int pitchAngle = constrain(90 + pidOutput[1], 0, 180);
        int yawAngle   = constrain(90 + pidOutput[2], 0, 180);

        // Output to servos
        servoRoll.write(rollAngle);
        servoPitch.write(pitchAngle);
        servoYaw.write(yawAngle);

        vTaskDelay(10 / portTICK_PERIOD_MS); // ~100Hz
    }
}

void displayOrientationTask(void *pvParameters) {
  while(1) {
    if(xSemaphoreTake(pass_angles_Semaphore, 0) == pdTRUE)
    {
    Serial.print(":INFO|");
    Serial.print(fusedAngle[0], 3);  // 3 decimal places
    Serial.print("|");
    Serial.print(fusedAngle[1], 3);
    Serial.print("|");
    Serial.print(fusedAngle[2], 3);
    Serial.println("|:");

    vTaskDelay(10 / portTICK_PERIOD_MS);
    }
  }
}

void setup() {
    Serial.begin(9600); 
    pinMode(2, OUTPUT);
    servoRoll.attach(SERVO_ROLL_PIN);
    servoPitch.attach(SERVO_PITCH_PIN);
    servoYaw.attach(SERVO_YAW_PIN);
    lastTime = millis();

    if (!IMU.begin()) 
    {
      while (1);
    }

    dataSemaphore = xSemaphoreCreateBinary();
    pass_angles_Semaphore = xSemaphoreCreateBinary();

    
    xTaskCreate(readSerialTask, "ReadSerialTask", 128, NULL, 1, NULL);
    xTaskCreate(commandChecker, "commandChecker", 128, NULL, 1, NULL);
    xTaskCreate(control_Loop , "control Loop" , 256 ,NULL , 1 , NULL);
    xTaskCreate(displayOrientationTask, "Display", 256, NULL, 1, NULL);
}

void loop() 
{
    // FreeRTOS handles tasks, so no need for code in loop()
}

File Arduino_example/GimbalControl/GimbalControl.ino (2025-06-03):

#include <Arduino_FreeRTOS.h>
#include <semphr.h>
#include <Wire.h>
#include <Adafruit_Sensor.h>
#include <Adafruit_ADXL345_U.h>
#include <Servo.h>

// Servo control
Servo servoRoll;
Servo servoPitch;
Servo servoYaw;

const int SERVO_ROLL_PIN = 9;
const int SERVO_PITCH_PIN = 10;
const int SERVO_YAW_PIN = 11;

// PID parameters (tune individually per axis)
float Kp[3] = {1.5, 1.5, 1.5};
float Ki[3] = {0.0, 0.0, 0.0};
float Kd[3] = {0.1, 0.1, 0.1};

// PID state
float errorSum[3] = {0, 0, 0};
float lastError[3] = {0, 0, 0};

// Angles: 0 = Roll, 1 = Pitch, 2 = Yaw
float measuredAngles[3] = {0, 0, 0};
float desiredAngles[3]  = {0, 0, 0};  // Set externally (e.g. via Serial)

unsigned long lastTime = 0;



/// defines 

#define PI  3.14159 
#define START_COMMAND_CHAR ':'
#define SEPARATE_VALUE_CHAR "|"


/////////////////// variables setting 
String receivedData;  // Buffer to store received data
SemaphoreHandle_t dataSemaphore;  // Semaphore for data synchronization
bool SpecialCharacterCapturing = false;
#define MAX_VALUES 3 




sensors_event_t event; 
Adafruit_ADXL345_Unified accel = Adafruit_ADXL345_Unified(12345);
///////////////////////////////////////
//sensor data config 
void displayRange(void)
{
  Serial.print  ("Range:         +/- "); 
  
  switch(accel.getRange())
  {
    case ADXL345_RANGE_16_G:
      Serial.print  ("16 "); 
      break;
    case ADXL345_RANGE_8_G:
      Serial.print  ("8 "); 
      break;
    case ADXL345_RANGE_4_G:
      Serial.print  ("4 "); 
      break;
    case ADXL345_RANGE_2_G:
      Serial.print  ("2 "); 
      break;
    default:
      Serial.print  ("?? "); 
      break;
  }  
  Serial.println(" g");  
}

// Task to read serial data
void readSerialTask(void *pvParameters) {
    while (1) {
      
        while (Serial.available()) {

            char c = Serial.read();

            if(c == START_COMMAND_CHAR){
              if(SpecialCharacterCapturing){
                //if already triggered it means it finished
                SpecialCharacterCapturing = false;
                xSemaphoreGive(dataSemaphore);
              }
              else{     
                //clearing data buffer and setting the character saving to true                           
                receivedData = "";
                SpecialCharacterCapturing = true;              
              }
            }
            else if(SpecialCharacterCapturing){
              receivedData += c;  
            }
        }

        vTaskDelay(10 / portTICK_PERIOD_MS);  // Small delay to avoid CPU overload
    }
}

// Task to write received serial data
void commandChecker(void *pvParameters) {
    while (1) {
        if (xSemaphoreTake(dataSemaphore, portMAX_DELAY) == pdTRUE) {
            Serial.print("Received: ");
            Serial.println(receivedData);

            if (receivedData.length() > 2) {
                // Trim leading and trailing delimiters
                Serial.println("data before triming");
                Serial.println(receivedData);
                String trimmed = receivedData.substring(0, receivedData.length() - 1);
                Serial.println("data after triming");
                Serial.println(trimmed);

                char command[50];
                trimmed.toCharArray(command, sizeof(command));

                char *token = strtok(command, SEPARATE_VALUE_CHAR);
                char *commandType = token;

                int valueIndex = 0;
                while ((token = strtok(NULL, SEPARATE_VALUE_CHAR)) != NULL && valueIndex < MAX_VALUES) {
                    desiredAngles[valueIndex++] = atof(token);
                }

                Serial.print("Command: ");
                Serial.println(commandType);

                for (int i = 0; i < valueIndex; i++) {
                    Serial.print("Value ");
                    Serial.print(i + 1);
                    Serial.print(": ");
                    Serial.println(desiredAngles[i]);
                }
            } else {
                Serial.println("Received data too short.");
            }

            receivedData = "";
        }

        vTaskDelay(10 / portTICK_PERIOD_MS);
    }
}

void control_Loop(void *pvParameters)
{
    float acc_measure[3];
    float pidOutput[3], error[3], dError[3];
    float dt;

    while (1)
    {
        // Timing
        unsigned long now = millis();
        dt = (now - lastTime) / 1000.0; // in seconds
        lastTime = now;

        // Get acceleration data
        accel.getEvent(&event);
        acc_measure[0] = event.acceleration.x;
        acc_measure[1] = event.acceleration.y;
        acc_measure[2] = event.acceleration.z;

        // Compute angles
        measuredAngles[0] = atan2(acc_measure[1], sqrt(acc_measure[0]*acc_measure[0] + acc_measure[2]*acc_measure[2])) * 180.0 / PI;  // Roll
        measuredAngles[1] = atan2(-acc_measure[0], sqrt(acc_measure[1]*acc_measure[1] + acc_measure[2]*acc_measure[2])) * 180.0 / PI;  // Pitch
        measuredAngles[2] = atan2(acc_measure[2], sqrt(acc_measure[2]*acc_measure[2] + acc_measure[0]*acc_measure[0])) * 180.0 / PI;  // Yaw 

        // PID control for Roll, Pitch, Yaw
        for (int i = 0; i < 3; i++) {
            error[i] = desiredAngles[i] - measuredAngles[i];
            errorSum[i] += error[i] * dt;
            dError[i] = (error[i] - lastError[i]) / dt;

            pidOutput[i] = Kp[i] * error[i] + Ki[i] * errorSum[i] + Kd[i] * dError[i];
            lastError[i] = error[i];
        }

        // Convert to servo angles
        int rollAngle  = constrain(90 + pidOutput[0], 0, 180);
        int pitchAngle = constrain(90 + pidOutput[1], 0, 180);
        int yawAngle   = constrain(90 + pidOutput[2], 0, 180);

        // Output to servos
        servoRoll.write(rollAngle);
        servoPitch.write(pitchAngle);
        servoYaw.write(yawAngle);

        // Optional: debug
        Serial.print("dt: "); Serial.print(dt, 4);
        Serial.print(" Roll: "); Serial.print(measuredAngles[0], 1);
        Serial.print(" Pitch: "); Serial.print(measuredAngles[1], 1);
        Serial.print(" Yaw: "); Serial.println(measuredAngles[2], 1);

        vTaskDelay(10 / portTICK_PERIOD_MS); // ~100Hz
    }
}


void displayOrientationTask(void *pvParameters) {
  while(1) {
    Serial.print("Roll: "); Serial.print(measuredAngles[0]);
    Serial.print(" | Pitch: "); Serial.print(measuredAngles[1]);
    Serial.print(" | Yaw: "); Serial.println(measuredAngles[2]);
    vTaskDelay(1000 / portTICK_PERIOD_MS);
  }
}
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

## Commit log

2025-06-03 changed arduino parser
    [schemat_extension_board.kicad_pcb, schemat_extension_board.kicad_sch]
2025-06-12 name clean-up
    [arm_1.stl, arm_2.stl, base.stl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]
2025-06-12 Adding CAD stuff
